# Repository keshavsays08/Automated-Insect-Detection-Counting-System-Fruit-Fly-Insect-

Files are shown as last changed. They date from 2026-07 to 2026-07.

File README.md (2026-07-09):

# Automated Insect Detection & Counting System

## 📌 Project Overview

A real-time fruit fly detection and counting system using **YOLOv8 deep learning** deployed on **Raspberry Pi 4**. This project combines computer vision, edge AI, and IoT to create an automated agricultural monitoring solution.

**Key Achievement**: 93% accuracy with automated counting, CSV logging, and custom 3D-printed hardware integration.

---

## 🎯 Problem Statement

Agricultural pest monitoring requires continuous manual observation, which is time-consuming and labor-intensive. This project automates fruit fly detection and counting using deep learning on edge devices for real-time monitoring.

---

## 💡 Solution Architecture

### High-Level Flow:

```
Data Collection → Annotation → Model Training → Pi Deployment → Real-Time Detection
     ↓              ↓              ↓                ↓               ↓
 1100+ Images  Roboflow       YOLOv8           Optimization    CSV Logging
```

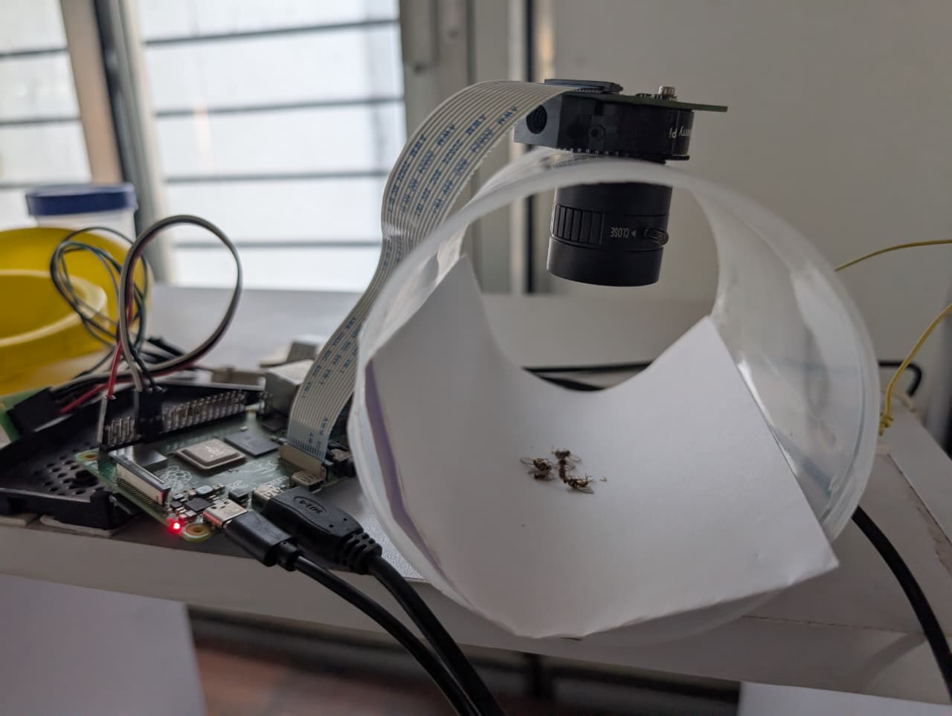
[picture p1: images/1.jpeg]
Initial Project Setup


---
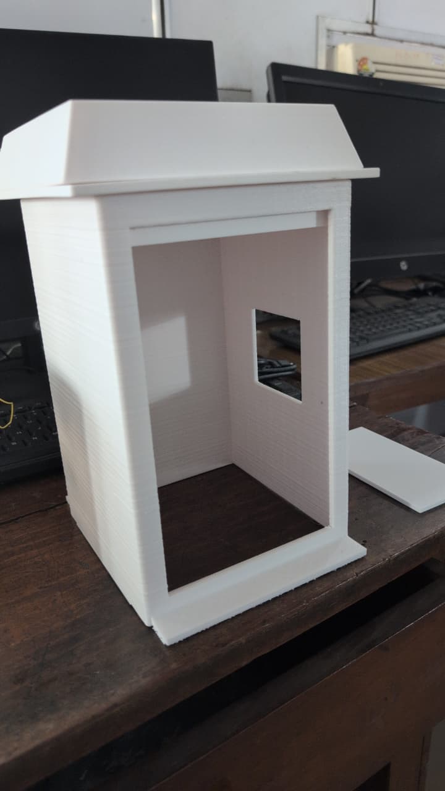
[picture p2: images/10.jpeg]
Final Project Setup


---

## 🛠️ Technology Stack

### Machine Learning
- **Framework**: PyTorch with YOLOv8
- **Dataset**: 520 annotated images
- **Annotation Tool**: Roboflow
- **Augmentation**: Flip, Rotation (±15°), 90° Rotate, Blur, Noise

### Hardware
- **Device**: Raspberry Pi 4 (4GB)
- **Camera**: HQ Camera Module (5MP)
- **3D Design**: Custom-printed enclosure

### Software
- **Computer Vision**: OpenCV
- **Data Processing**: Pandas, NumPy
- **Logging**: CSV with timestamps
- **Real-time Display**: OpenCV visualization

---

## 📊 Project Results

### Model Performance

| Metric | Value |
|---|---|
| **mAP@50** | 93% |
| **Precision** | 90.1% |
| **Recall** | 93.0% |
| **Training Data** | 520 annotated images |
| **Real-time FPS** | 5-10 FPS on Pi 4 |

---

## 🎬 Project Pipeline

### Phase 1: Data Collection
- Captured **1,100+ images** on Raspberry Pi HQ Camera
- Various scenarios: different lighting, angles, close-ups, far shots
- Consistent dome setup for standardization

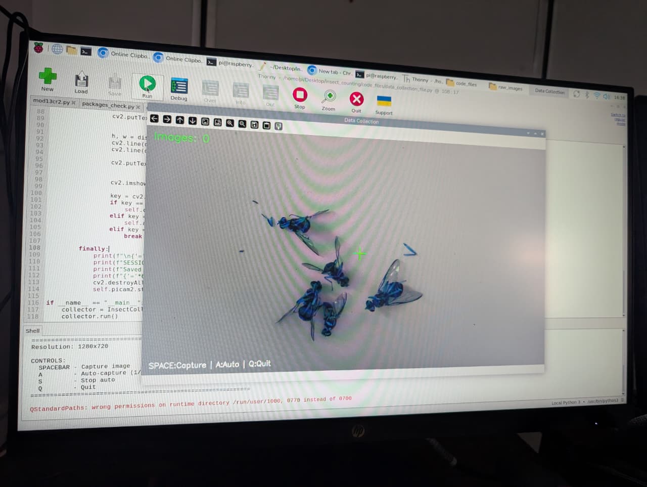
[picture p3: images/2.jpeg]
During Data Collection


### Phase 2: Data Annotation
- Annotated **520 images** using Roboflow
- Manual bounding box creation around each fruit fly
- ~2-3 hours of annotation work
- Single class: "fruit fly"

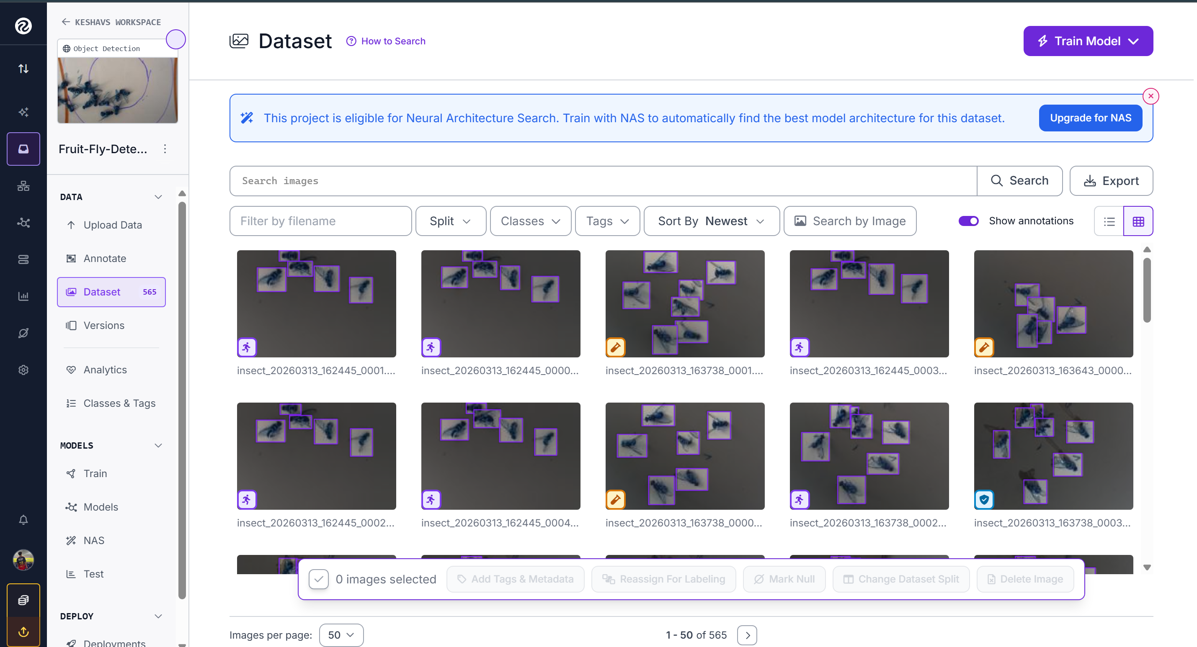
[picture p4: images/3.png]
During Data Annotation


### Phase 3: Model Training
- **Framework**: YOLOv8 Nano (optimized for Pi)
- **Training Environment**: PC with Python + PyTorch
- **Augmentation**: 3x multiplier for better generalization
- **Result**: 93% mAP@50 in just 8 epochs (early stop due to excellent performance)

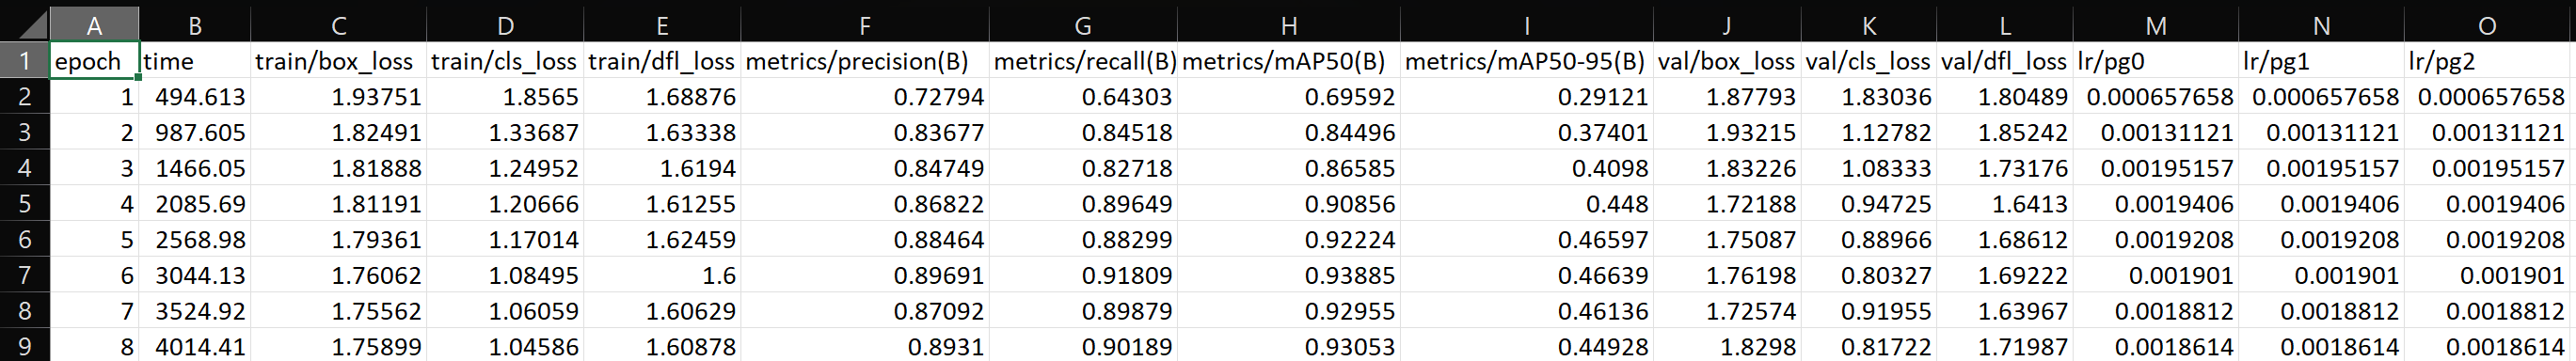
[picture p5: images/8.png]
Training Results


### Phase 4: PC Simulation Testing
- Created Python simulator to test model on PC
- Tested on 30 unannotated images
- Live detection display with 15-second intervals
- CSV logging of results

### Phase 5: Raspberry Pi Deployment
- Installed 64-bit Raspberry Pi OS
- Optimized PyTorch inference (CPU-only)
- Deployed real-time detection system
- Automated snapshot capture every 60 seconds

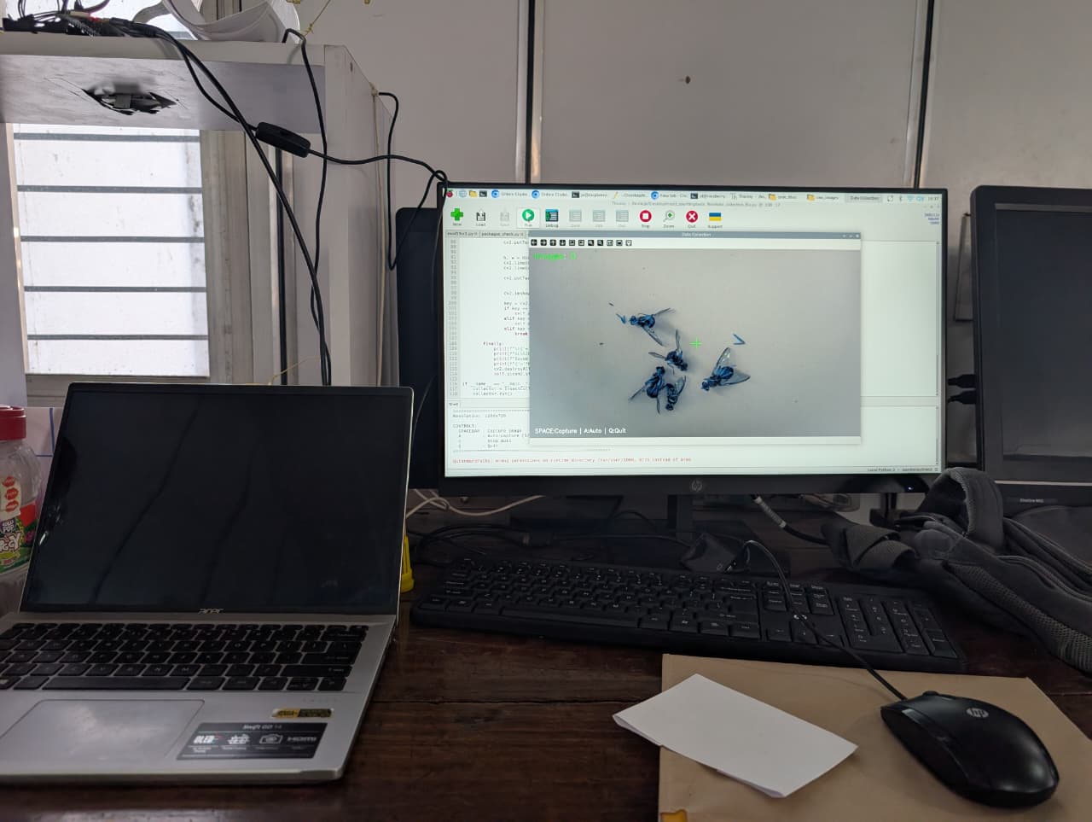
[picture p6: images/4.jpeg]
During Deployment


### Phase 6: Hardware Integration
- **3D Enclosure Design**: Custom-printed trap housing
- **Components**: Camera mount, Pi housing, pheromone chamber
- **Purpose**: Integration point for field deployment

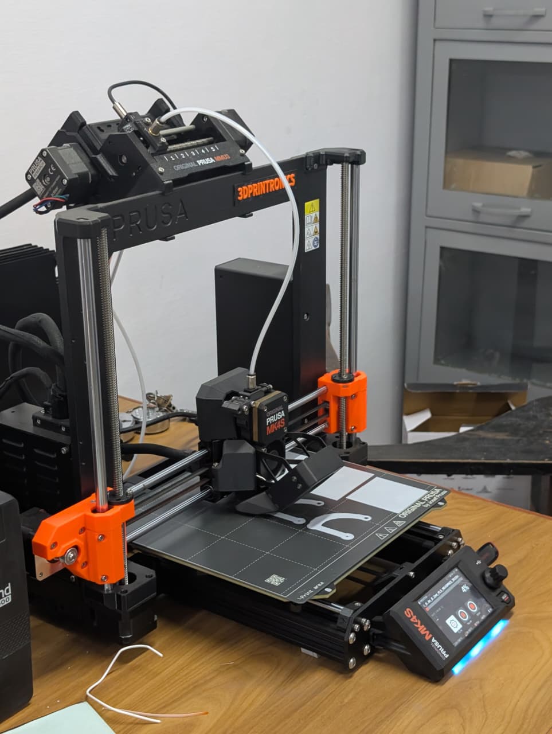
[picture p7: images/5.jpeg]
During 3D Printing


---

## ✨ Key Features

### Real-Time Detection
- Live camera feed with bounding boxes
- Fruit fly count displayed on screen
- FPS monitoring
- Confidence scores for each detection

### Automated Logging
- CSV file with timestamp, count, and confidence
- Automatic snapshot capture every 60 seconds
- Session statistics and duration tracking
- Organized data structure for analysis

### User Controls
- **SPACE**: Pause/Resume detection
- **S**: Save snapshot manually
- **Q**: Quit and display statistics

### Hardware Integration
- Custom 3D-printed enclosure
- Professional mounting for Pi and camera
- Pheromone trap integration design
- Field-deployment ready

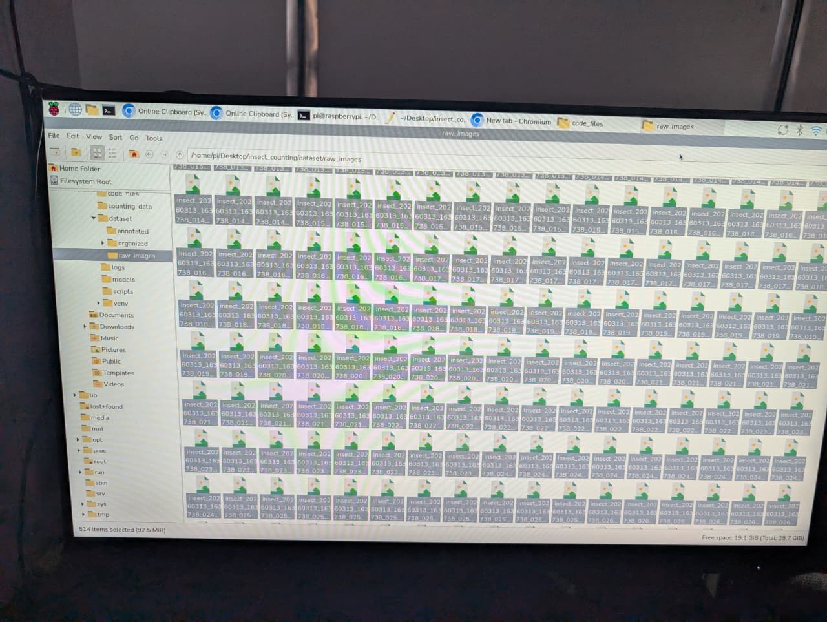
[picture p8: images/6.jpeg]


---

## 📈 Metrics & Performance

### Detection Accuracy
- **93% mAP@50**: Industry-competitive accuracy
- **90.1% Precision**: Minimal false positives
- **93% Recall**: Excellent fly detection rate

### System Performance
- **Processing Speed**: 5-10 FPS on Raspberry Pi 4
- **Memory Usage**: ~400-600MB RAM
- **CPU Usage**: 60-80%
- **Model Size**: ~20MB (optimized)

### Data Logging
- **CSV Format**: Timestamp, count, confidence, processing time
- **Snapshot Interval**: Every 60 seconds (configurable)
- **Session Tracking**: Duration, total frames, total detections

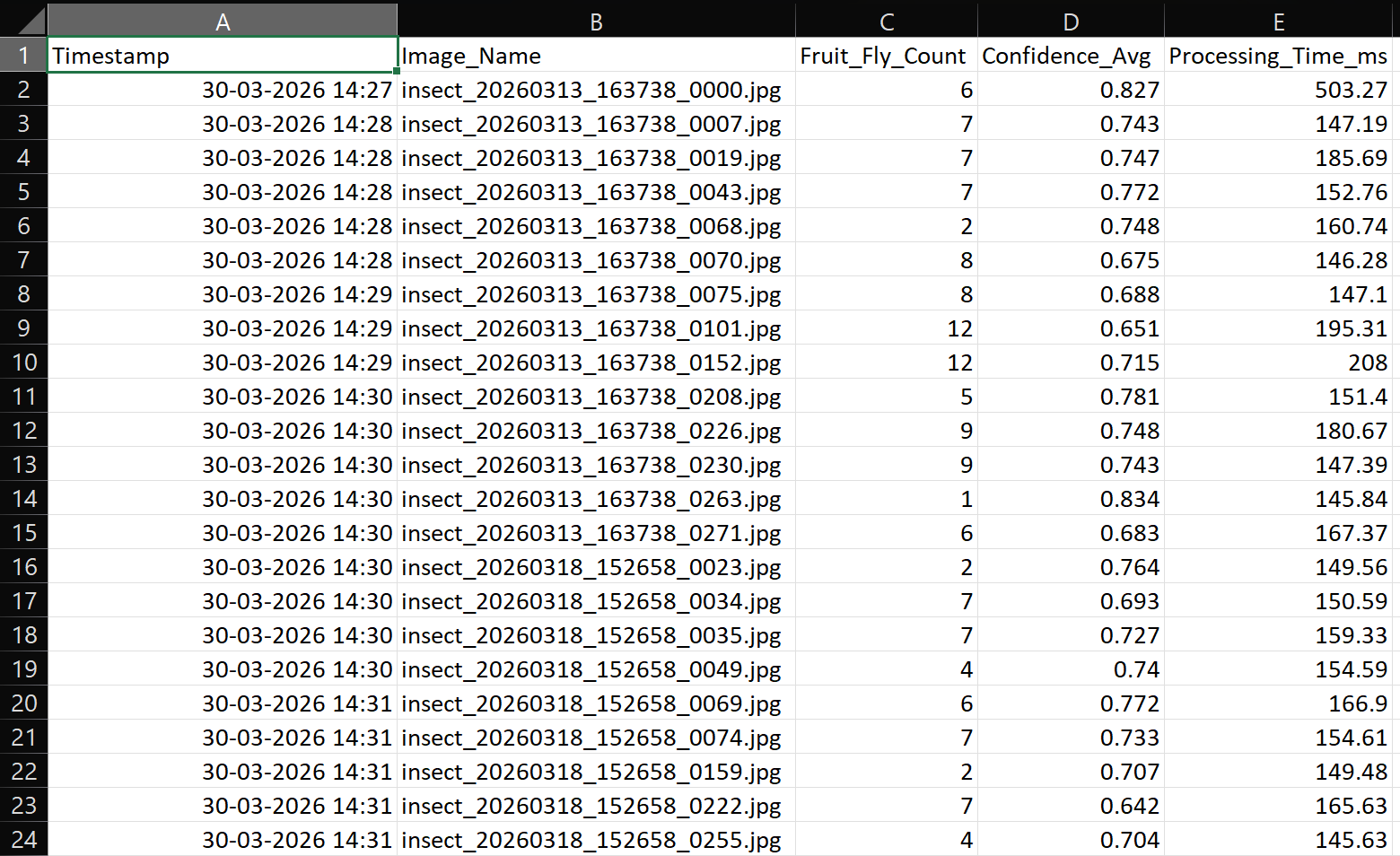
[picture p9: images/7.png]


---

## 🚀 How to Use

### Quick Start

```bash
# 1. Clone repository
git clone https://github.com/keshaysays08/Automated-Insect-Detection-Counting-System.git
cd Automated-Insect-Detection-Counting-System

# 2. Install dependencies
pip install -r requirements.txt

# 3. Download dataset
python scripts/download_dataset.py

# 4. Run real-time detection
python scripts/realtime_detection.py
```

### Output Files
After running the system, you'll get:
- `detection_logs/detection_log_YYYYMMDD_HHMMSS.csv` - Detailed detection data
- `detection_logs/captured_detections/` - Snapshot images with detections

### Configurable Parameters
Edit `config/config.yaml` to adjust:
- Confidence threshold (0.0-1.0)
- Frame delay between captures
- Snapshot capture interval

---

## 🔬 Dataset Information

### Statistics
- **Total Images Collected**: 1,100+
- **Images Annotated**: 520
- **Classes**: 1 (fruit fly)
- **Train/Val/Test Split**: 70/20/10

### Data Augmentation
- Horizontal flip
- Rotation (±15°)
- 90° rotations (all directions)
- Blur (up to 1px)
- Noise (up to 1.68%)
- **Augmentation Multiplier**: 3x

### Download Dataset
```bash
python scripts/download_dataset.py
```
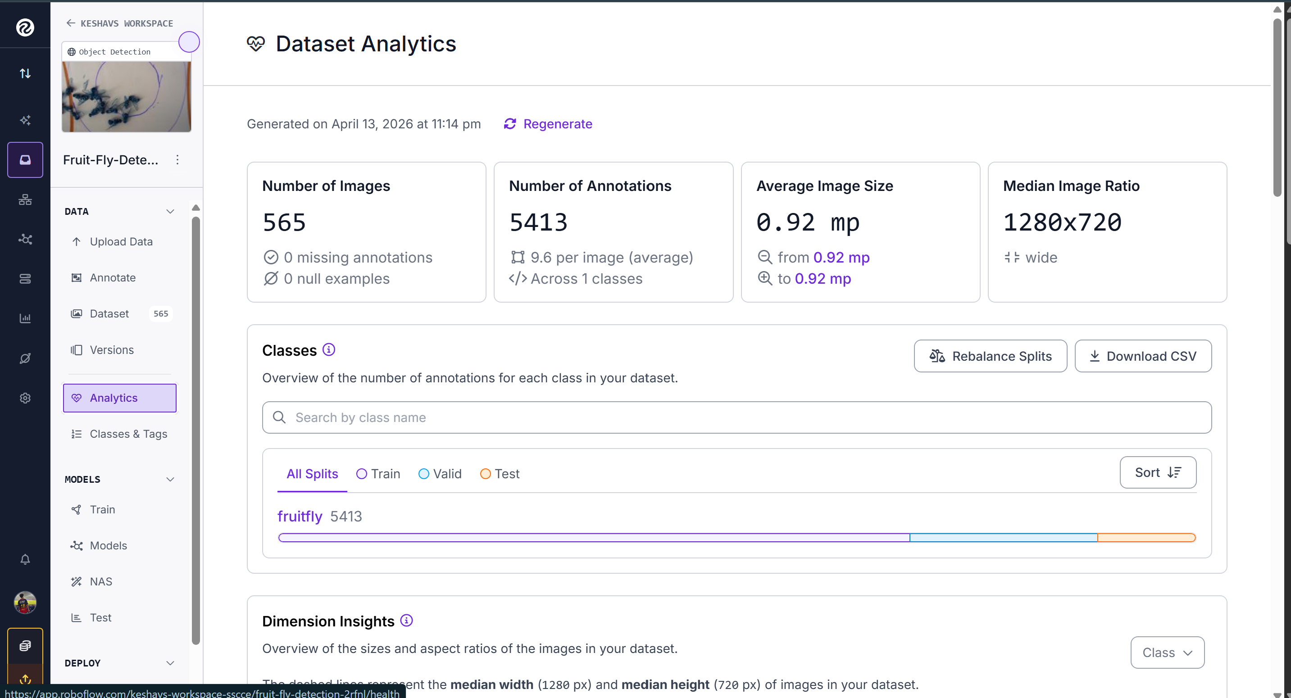
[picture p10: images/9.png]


---

## 🔧 Technical Details

### Environment Setup
- **Python**: 3.11+
- **OS**: 64-bit Raspberry Pi OS (Bookworm)
- **Virtual Environment**: Conda with system packages
- **GPU**: CPU-only (optimized for Pi)

### Dependencies
All dependencies listed in `requirements.txt`:
- torch==2.0.1
- ultralytics==8.0.200
- opencv-python==4.8.1
- pandas==2.0.3
- And others for full pipeline

### Model Architecture
- **Base Model**: YOLOv8 Nano
- **Framework**: PyTorch → TorchScript optimization
- **Input Size**: 640×480 (adjustable)
- **Output**: Bounding boxes with confidence scores

---

## 📁 Project Structure

```
Automated-Insect-Detection-Counting-System/
├── scripts/
│   ├── realtime_detection.py    # Main detection system
│   └── download_dataset.py       # Roboflow dataset download
├── runs/
│   └── best.pt                   # Trained YOLO model
├── config/
│   └── config.yaml               # Configuration parameters
├── hardware/
│   └── assembly_guide.md         # 3D enclosure assembly
├── docs/
│   ├── SETUP.md                  # Installation guide
│   └── USAGE.md                  # Usage instructions
├── README.md                      # This file
├── requirements.txt               # Python dependencies
└── .gitignore                     # Git ignore rules
```

---

## 🤝 Author

**Keshav Gairola**
- Portfolio: [keshav-gairola-portfolio.vercel.app](https://keshav-gairola-portfolio.vercel.app)
- GitHub: [@keshaysays08](https://github.com/keshaysays08)
- Email: keshavsays08@gmail.com

---

## 📝 License

This project is licensed under the MIT License - see the LICENSE file for details.

---

## 🙏 Acknowledgments

- YOLOv8 by Ultralytics
- Roboflow for annotation platform
- Raspberry Pi Foundation
- PyTorch community

---

**Last Updated**: April 2026

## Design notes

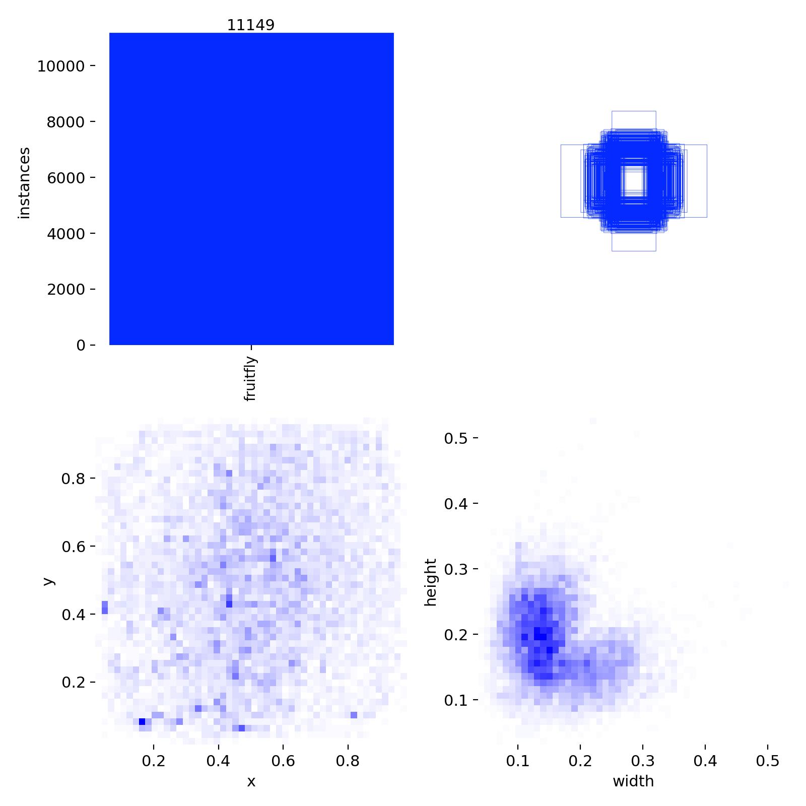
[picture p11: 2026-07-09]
runs/detect/fruitfly_model/v1/labels.jpg

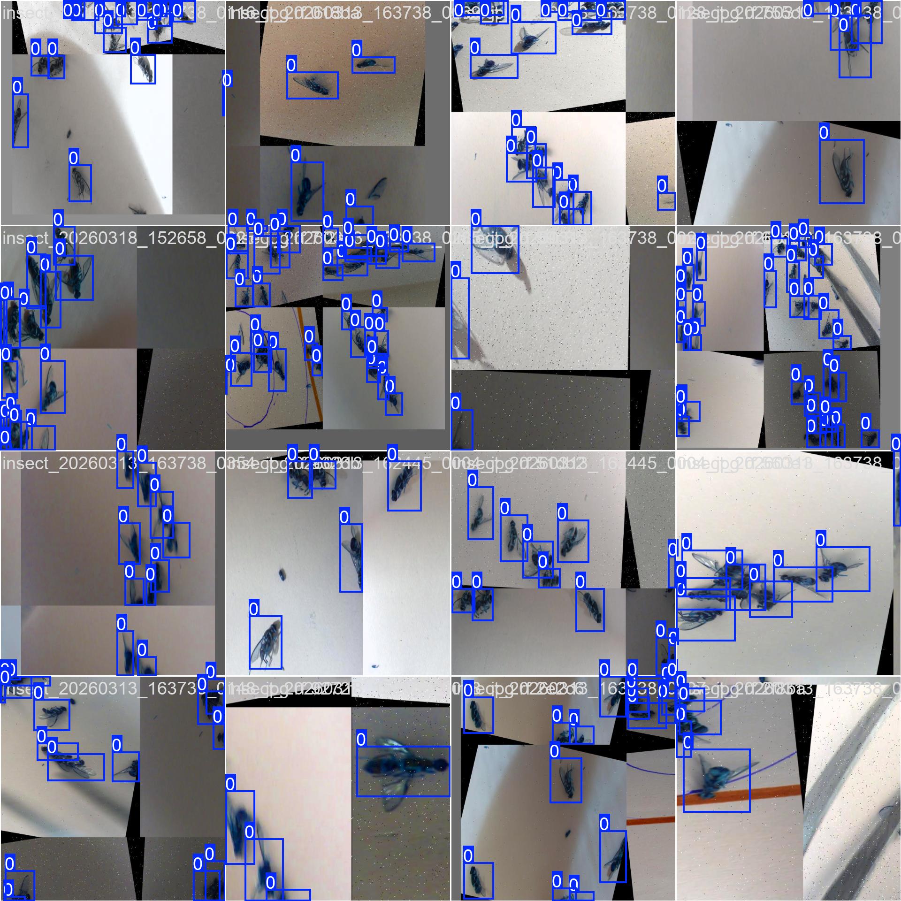
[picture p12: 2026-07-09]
runs/detect/fruitfly_model/v1/train_batch2.jpg

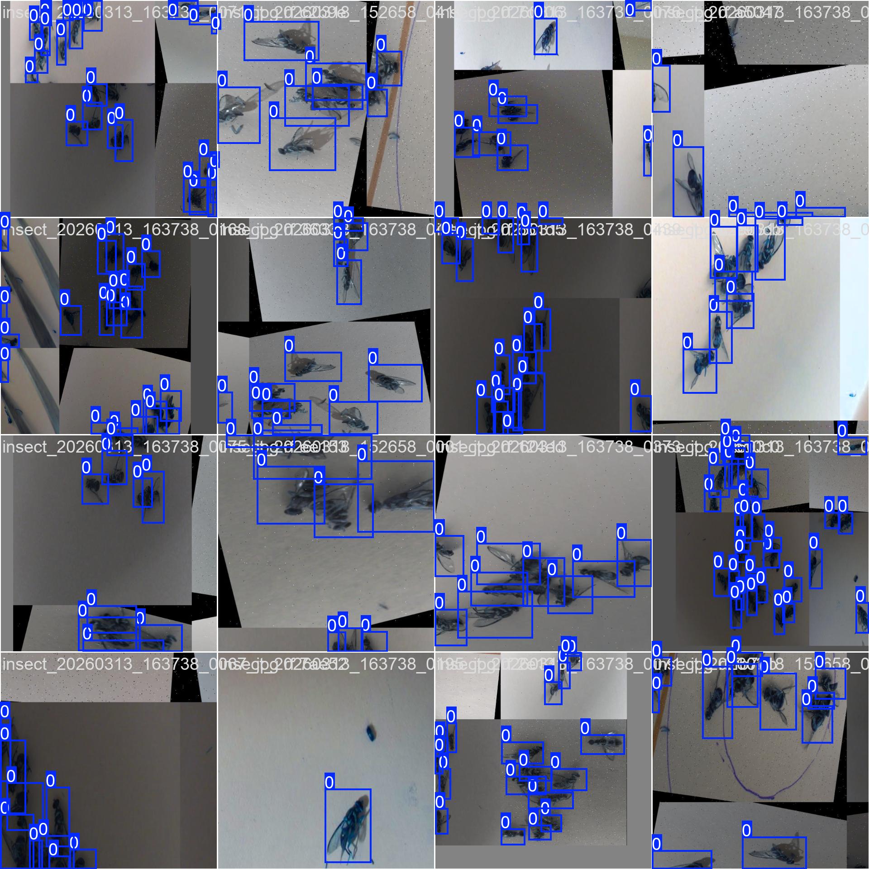
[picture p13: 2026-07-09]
runs/detect/fruitfly_model/v1/train_batch1.jpg

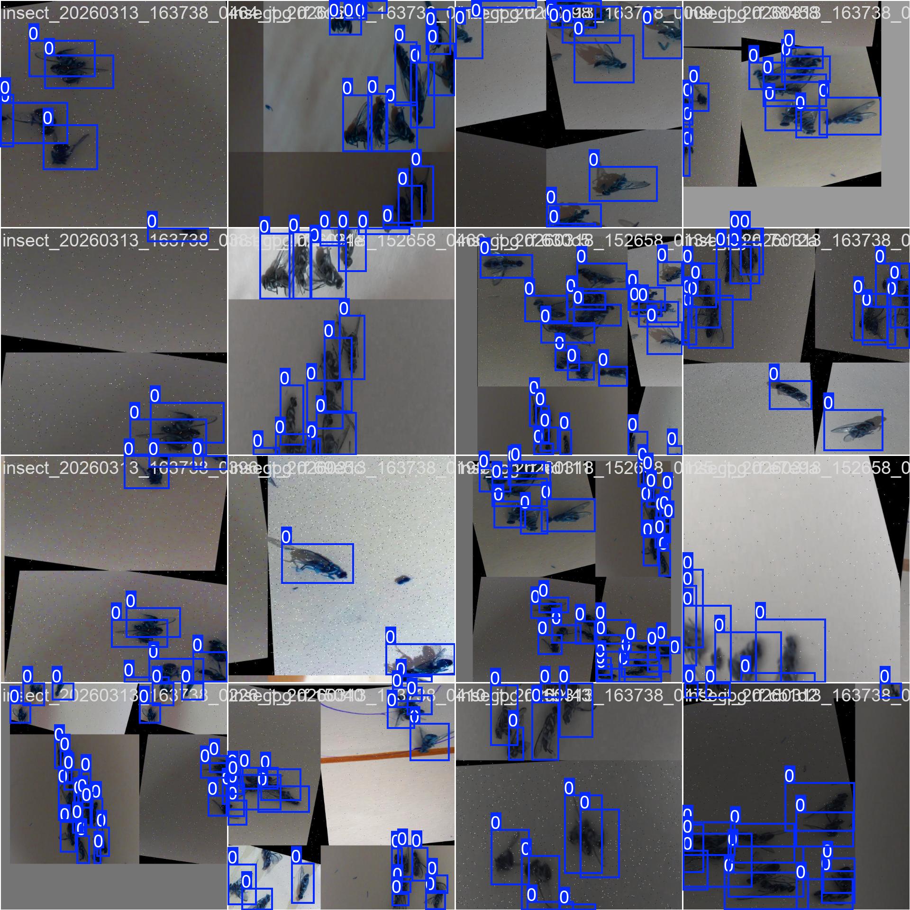
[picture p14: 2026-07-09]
runs/detect/fruitfly_model/v1/train_batch0.jpg

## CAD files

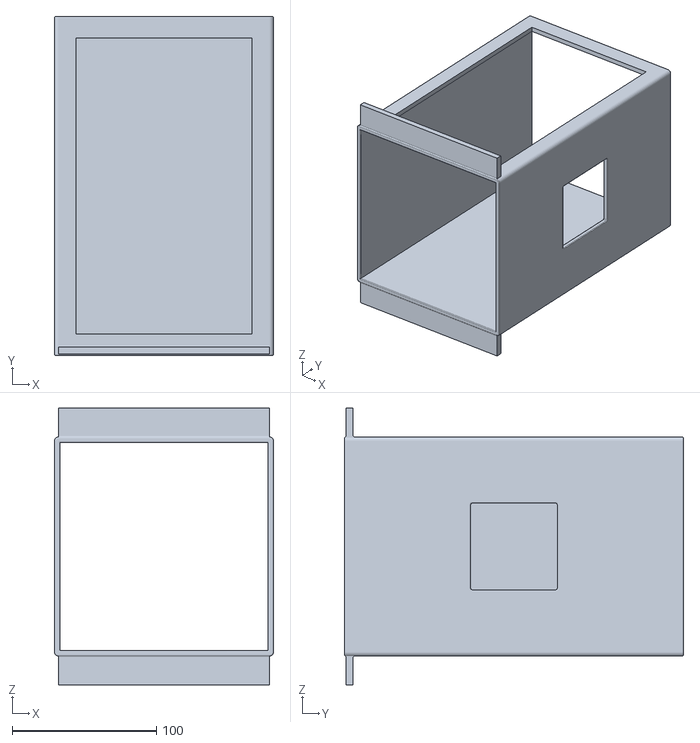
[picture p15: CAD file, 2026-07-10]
hardware/FINAL_TrapdoorMainChamber.stl
152.0 x 235.0 x 192.0

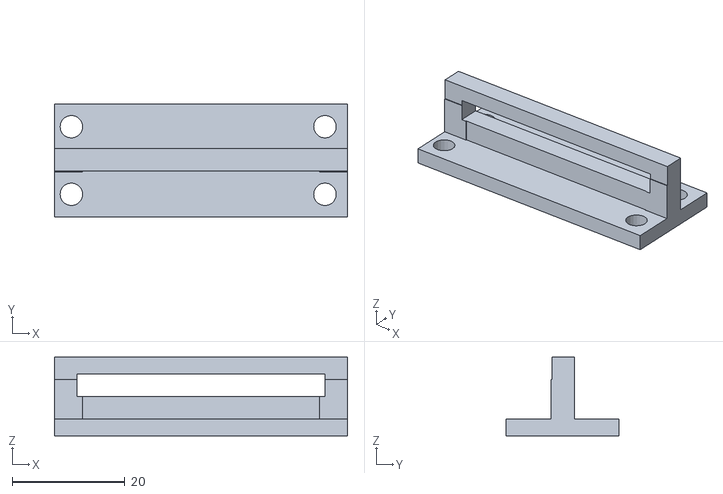
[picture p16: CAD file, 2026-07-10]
hardware/ServoMotor/Door_part2.stl
52.0 x 20.0 x 14.0

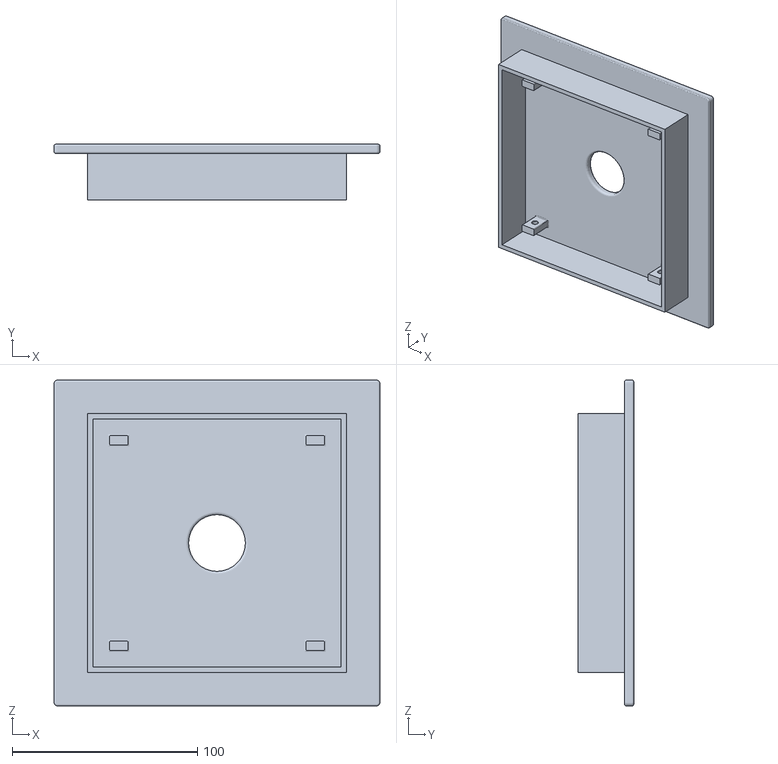
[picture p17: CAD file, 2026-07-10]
hardware/FINAL_TopLidSurface.stl
176.0 x 30.0 x 176.0

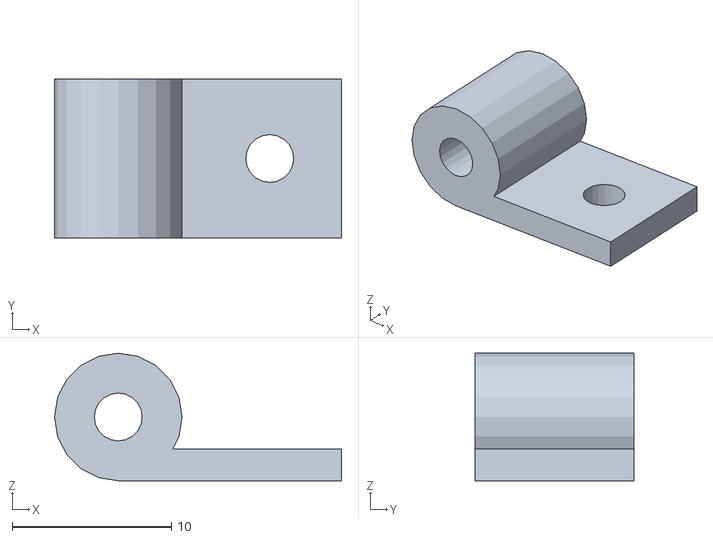
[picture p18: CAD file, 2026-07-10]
hardware/ServoMotor/Door_part0.stl
18.0 x 10.0 x 8.00

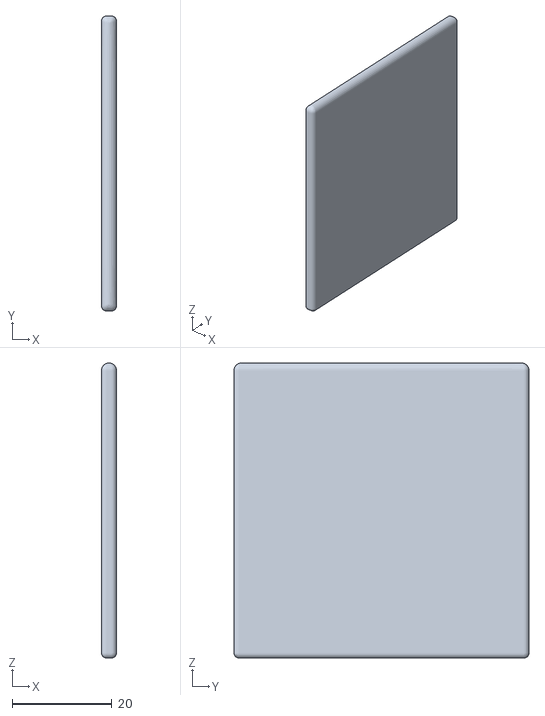
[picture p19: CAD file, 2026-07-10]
hardware/FINAL_FlapDoor.stl
3.00 x 59.0 x 59.0

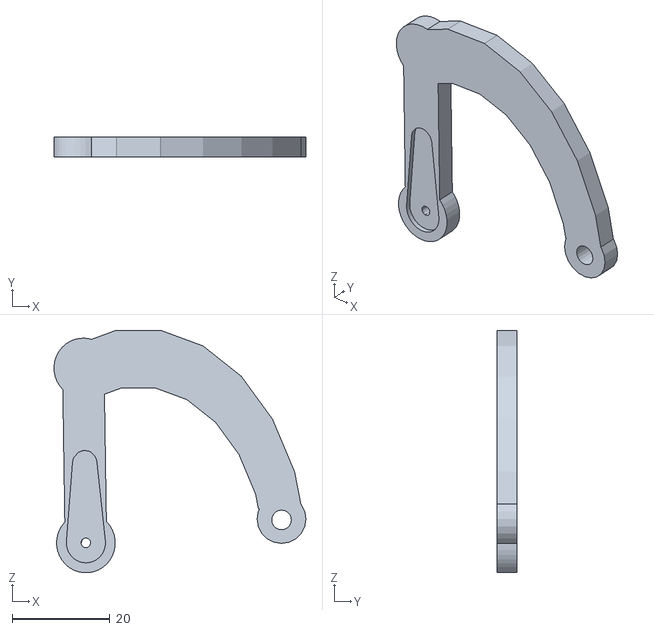
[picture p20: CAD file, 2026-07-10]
hardware/ServoMotor/ServoHorn.stl
51.5 x 4.00 x 49.6

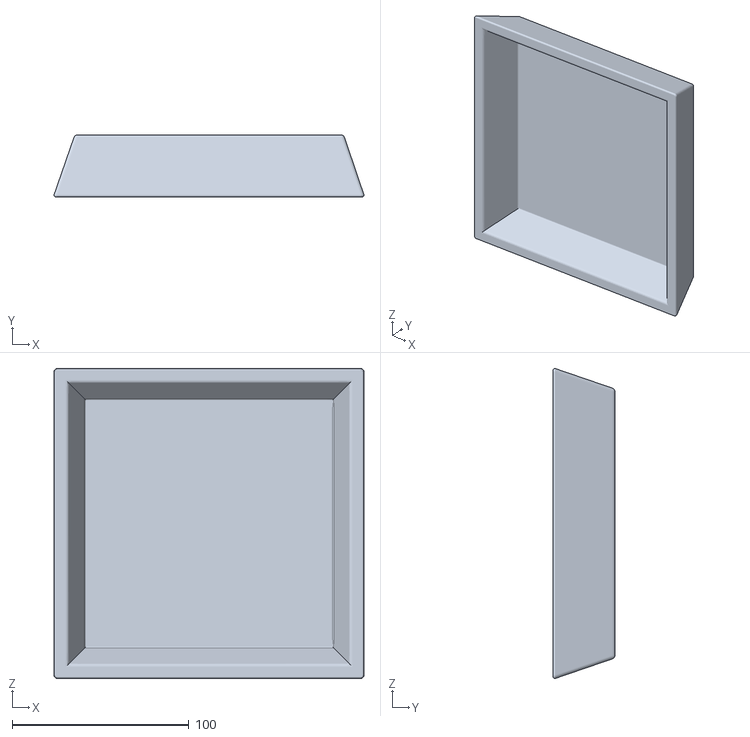
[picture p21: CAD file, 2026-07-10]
hardware/FINAL_TopLid.stl
175.2 x 35.0 x 175.2

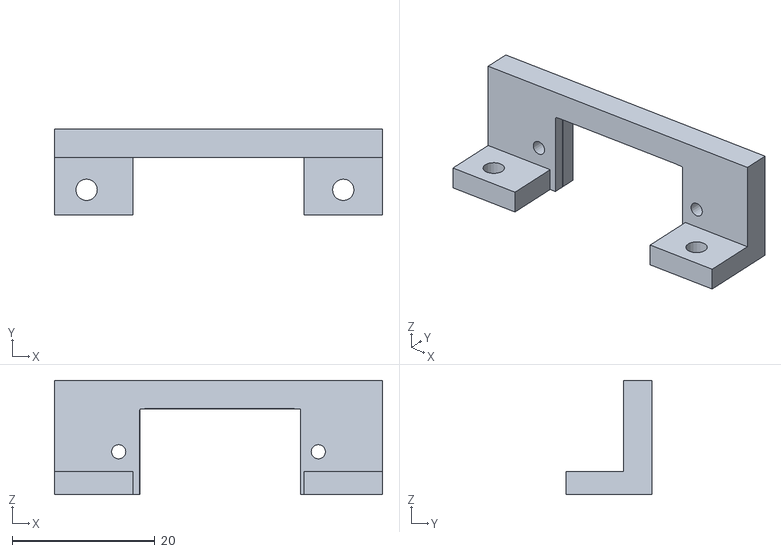
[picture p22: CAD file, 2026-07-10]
hardware/ServoMotor/Servo_Mount.stl
46.0 x 12.0 x 16.0

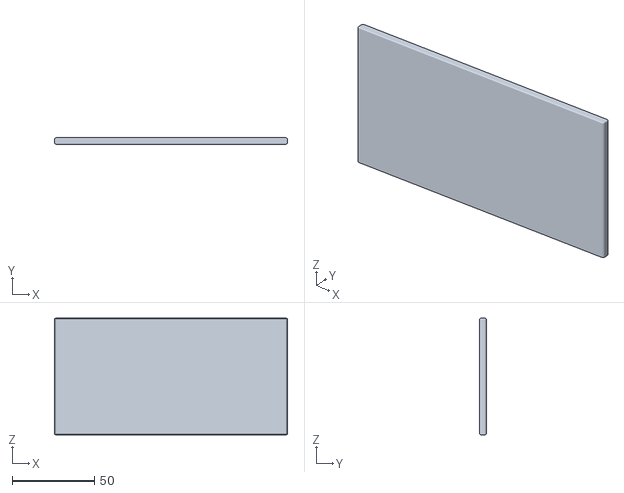
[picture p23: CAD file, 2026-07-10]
hardware/FINAL_TrapdoorFloor.stl
142.0 x 4.00 x 71.0

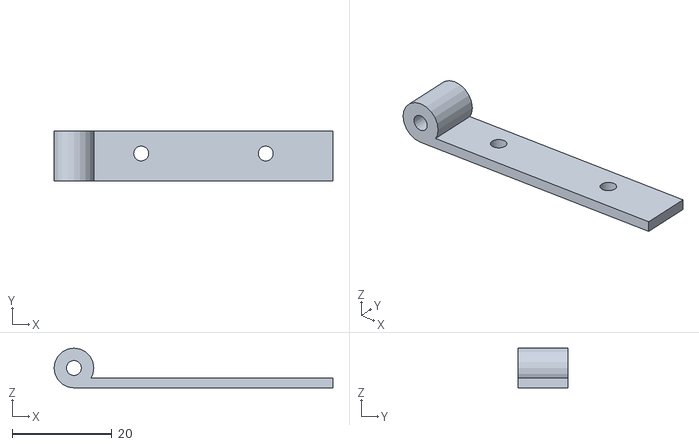
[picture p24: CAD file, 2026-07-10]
hardware/ServoMotor/Door_part1.stl
56.0 x 10.0 x 8.00

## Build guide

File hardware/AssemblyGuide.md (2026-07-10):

# ASSEMBLY GUIDE:
Dimensions: 152 mm (L) x 152 mm (W) x 235 mm (H) | System: Dual-Servo Automated Trapdoor  
Chassis Thickness: 4.0mm

## BILL OF MATERIALS (BOM)

3D Printed Parts (PLA/PETG, 50% Gyroid Infill):
  - 1x Main Chassis Shell (with Acrylic window slot & Inlet hole)
  - 1x Top Lid (with 30.4mm centered camera hole & LED channels)
  - 2x Trapdoor Panels (Left and Right floor halves, 5.0mm thick)
  - 1x Inlet Swing Door

Sourced Hardware:
  - 3x TowerPro SG90 / MG90S Micro Servos (Inlet & Trapdoor actuation)
  - 1x Transparent Acrylic Sheet (7" x 5" x 2mm or 3mm)
  - M3 Screws (12mm for servo mounts)
  - Waterproof LED Strip Segment

## ASSEMBLY STEPS

### STEP 1: WINDOW INTERFACE

- Fix the 7" x 5" Acrylic Sheet down onto the front face of the Main Chassis. Ensure flush fit.  

### STEP 2: INLET SERVO & DOOR

- Fix the Servo Mount piece and the door pieces as demonstrated in the video below.
- Mount the first Micro Servo into the designated place in the mount. Secure using M2/M3 self-tapping screws.
- Position the Inlet Swing Door over the inlet hole. Insert the 3D-printed hinge pin into the chassis socket.
- Connect the Servo Horn to the door via the servo door hinge (CAD File named Servo Horn).  
  
Refer to this video: https://www.youtube.com/shorts/rI9qZ3FkhSA

### STEP 3: 2-PANEL TRAPDOOR MECHANISM

- Take the Left and Right Trapdoor Panels. Align their integrated hinge axles with the corresponding socket holes at the base of the chassis.
- Fit the panels so they meet in the center with the modeled 0.5mm clearance gap.
- Mount the two secondary actuation servo into the the chassis in the same fashion as the inlet chamber door mechanism. One servo motor on each side.

### STEP 4: LID & INTERNAL UTILITIES

- Insert the 30mm camera lens module into the centered 30.4mm counterbore seat on the Top Lid Surface. Fasten via the 4x modeled M3 standoffs.
- Press-fit or adhesive-bond the LED strip into the internal perimeter under the lid. Route the wiring out through the rear notch.
- Thread your bait/lure onto the internal ceiling hooks.
- Fit the Top Lid on top of the Top Lid Surface to secure everything.

### STEP 5: FINAL INTEGRATION

- Align the Top Lid Surface with the Main Chassis rim.
- Position the enclosure over your collection chamber/bucket. Secure the corners using the physical L-brackets and M3 hardware into the pre-modeled pilot holes.
---
#### MECHANICAL VERIFICATION & TOLERANCES  

- **Clearance Verification**: Ensure the 0.5mm air gap between the trapdoor panels and the inner walls is clear of stray filament strings.
- **Axis Alignment**: The panels must fall completely vertical under gravity when the servo linkage retracts to clear the path for disposal.

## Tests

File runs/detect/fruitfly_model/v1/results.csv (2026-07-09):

epoch | time | train/box_loss | train/cls_loss | train/dfl_loss | metrics/precision(B) | metrics/recall(B) | metrics/mAP50(B) | metrics/mAP50-95(B) | val/box_loss | val/cls_loss | val/dfl_loss | lr/pg0 | lr/pg1 | lr/pg2
1 | 494.613 | 1.93751 | 1.8565 | 1.68876 | 0.72794 | 0.64303 | 0.69592 | 0.29121 | 1.87793 | 1.83036 | 1.80489 | 0.000657658 | 0.000657658 | 0.000657658
2 | 987.605 | 1.82491 | 1.33687 | 1.63338 | 0.83677 | 0.84518 | 0.84496 | 0.37401 | 1.93215 | 1.12782 | 1.85242 | 0.00131121 | 0.00131121 | 0.00131121
3 | 1466.05 | 1.81888 | 1.24952 | 1.6194 | 0.84749 | 0.82718 | 0.86585 | 0.4098 | 1.83226 | 1.08333 | 1.73176 | 0.00195157 | 0.00195157 | 0.00195157
4 | 2085.69 | 1.81191 | 1.20666 | 1.61255 | 0.86822 | 0.89649 | 0.90856 | 0.448 | 1.72188 | 0.94725 | 1.6413 | 0.0019406 | 0.0019406 | 0.0019406
5 | 2568.98 | 1.79361 | 1.17014 | 1.62459 | 0.88464 | 0.88299 | 0.92224 | 0.46597 | 1.75087 | 0.88966 | 1.68612 | 0.0019208 | 0.0019208 | 0.0019208
6 | 3044.13 | 1.76062 | 1.08495 | 1.6 | 0.89691 | 0.91809 | 0.93885 | 0.46639 | 1.76198 | 0.80327 | 1.69222 | 0.001901 | 0.001901 | 0.001901
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

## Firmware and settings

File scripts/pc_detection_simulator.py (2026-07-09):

#!/usr/bin/env python3
"""
Fruit Fly Detection - PC Simulator
Simulates the Raspberry Pi detection system on PC
Tests model on images with automatic timing and CSV logging
"""

import cv2
import os
from datetime import datetime
import csv
from pathlib import Path
from ultralytics import YOLO
import time

class FruitFlySimulator:
    def __init__(self, model_path, images_folder, output_folder="simulation_results"):
        """
        Initialize the simulator
        
        Args:
            model_path: Path to best.pt model file
            images_folder: Folder containing test images
            output_folder: Where to save results
        """
        # Load model
        print("Loading model...")
        self.model = YOLO(model_path)
        print(f"✓ Model loaded: {model_path}")
        
        # Setup folders
        self.images_folder = Path(images_folder)
        self.output_folder = Path(output_folder)
        self.output_folder.mkdir(exist_ok=True)
        
        # Create subfolders
        self.annotated_folder = self.output_folder / "annotated_images"
        self.annotated_folder.mkdir(exist_ok=True)
        
        # Get image files
        self.image_files = sorted([
            f for f in self.images_folder.glob('*')
            if f.suffix.lower() in ['.jpg', '.jpeg', '.png', '.bmp']
        ])
        
        print(f"✓ Found {len(self.image_files)} images")
        
        # CSV setup
        self.csv_path = self.output_folder / f"detection_log_{datetime.now().strftime('%Y%m%d_%H%M%S')}.csv"
        self._initialize_csv()
        
        # Statistics
        self.total_detections = 0
        self.current_index = 0
        self.detection_results = []
        
        # Display settings
        self.display_time = 15  # seconds per image
        self.confidence_threshold = 0.5
        
    def _initialize_csv(self):
        """Create CSV file with headers"""
        with open(self.csv_path, 'w', newline='') as f:
            writer = csv.writer(f)
            writer.writerow([
                'Timestamp',
                'Image_Name', 
                'Fruit_Fly_Count',
                'Confidence_Avg',
                'Processing_Time_ms'
            ])
        print(f"✓ CSV log created: {self.csv_path}")
    
    def _log_detection(self, image_name, count, avg_confidence, processing_time):
        """Log detection to CSV"""
        timestamp = datetime.now().strftime('%Y-%m-%d %H:%M:%S')
        
        with open(self.csv_path, 'a', newline='') as f:
            writer = csv.writer(f)
            writer.writerow([
                timestamp,
                image_name,
                count,
                f"{avg_confidence:.3f}" if count > 0 else "N/A",
                f"{processing_time:.2f}"
            ])
        
        # Store for statistics
        self.detection_results.append({
            'timestamp': timestamp,
            'image': image_name,
            'count': count
        })
    
    def detect_on_image(self, image_path):
        """Run detection on single image"""
        # Read image
        img = cv2.imread(str(image_path))
        if img is None:
            print(f"Error: Could not read {image_path}")
            return None
        
        # Run detection
        start_time = time.time()
        results = self.model(img, conf=self.confidence_threshold, verbose=False)
        processing_time = (time.time() - start_time) * 1000  # ms
        
        # Extract results
        boxes = results[0].boxes
        count = len(boxes)
        
        # Calculate average confidence
        avg_confidence = 0
        if count > 0:
            confidences = boxes.conf.cpu().numpy()
            avg_confidence = confidences.mean()
        
        # Draw annotations
        annotated_img = results[0].plot()
        
        # Add overlay information
        self._add_overlay(annotated_img, image_path.name, count, avg_confidence, processing_time)
        
        # Log to CSV
        self._log_detection(image_path.name, count, avg_confidence, processing_time)
        
        # Save annotated image
        save_path = self.annotated_folder / f"annotated_{image_path.name}"
        cv2.imwrite(str(save_path), annotated_img)
        
        return {
            'image': annotated_img,
            'count': count,
            'confidence': avg_confidence,
            'processing_time': processing_time
        }
    
    def _add_overlay(self, img, filename, count, confidence, proc_time):
        """Add information overlay to image"""
        h, w = img.shape[:2]
        
        # Semi-transparent background for text
        overlay = img.copy()
        cv2.rectangle(overlay, (0, 0), (w, 120), (0, 0, 0), -1)
        cv2.addWeighted(overlay, 0.6, img, 0.4, 0, img)
        
        # Add text information
        y_offset = 30
        cv2.putText(img, f"Image: {filename}", (10, y_offset),
                   cv2.FONT_HERSHEY_SIMPLEX, 0.7, (255, 255, 255), 2)
        
        y_offset += 30
        cv2.putText(img, f"Fruit Flies Detected: {count}", (10, y_offset),
                   cv2.FONT_HERSHEY_SIMPLEX, 0.8, (0, 255, 0), 2)
        
        y_offset += 30
        if count > 0:
            cv2.putText(img, f"Avg Confidence: {confidence:.2%}", (10, y_offset),
                       cv2.FONT_HERSHEY_SIMPLEX, 0.6, (255, 255, 255), 2)
        
        # Progress indicator
        progress_text = f"Image {self.current_index + 1}/{len(self.image_files)}"
        cv2.putText(img, progress_text, (w - 250, 30),
                   cv2.FONT_HERSHEY_SIMPLEX, 0.7, (255, 255, 0), 2)
    
    def _print_statistics(self):
        """Print session statistics"""
        print("\n" + "="*60)
        print("SESSION STATISTICS")
        print("="*60)
        
        total_images = len(self.detection_results)
        total_flies = sum(r['count'] for r in self.detection_results)
        avg_per_image = total_flies / total_images if total_images > 0 else 0
        
        images_with_flies = sum(1 for r in self.detection_results if r['count'] > 0)
        detection_rate = (images_with_flies / total_images * 100) if total_images > 0 else 0
        
        print(f"Total images processed: {total_images}")
        print(f"Total fruit flies detected: {total_flies}")
        print(f"Average flies per image: {avg_per_image:.2f}")
        print(f"Images with flies: {images_with_flies} ({detection_rate:.1f}%)")
        print(f"Images without flies: {total_images - images_with_flies}")
        print(f"\nResults saved to: {self.output_folder}")
        print(f"CSV log: {self.csv_path}")
        print(f"Annotated images: {self.annotated_folder}")
        print("="*60 + "\n")
    
    def run_auto_mode(self):
        """Run automatic slideshow mode"""
        print("\n" + "="*60)
        print("AUTOMATIC MODE - PC SIMULATION")
        print("="*60)
        print(f"Display time: {self.display_time} seconds per image")
        print("Controls:")
        print("  SPACE - Next image immediately")
        print("  P     - Pause/Resume auto-advance")
        print("  Q     - Quit")
        print("="*60 + "\n")
        
        paused = False
        
        for idx, image_path in enumerate(self.image_files):
            self.current_index = idx
            
            print(f"\n[{idx+1}/{len(self.image_files)}] Processing: {image_path.name}")
            
            # Detect
            result = self.detect_on_image(image_path)
            if result is None:
                continue
            
            print(f"  → Detected: {result['count']} flies")
            print(f"  → Confidence: {result['confidence']:.2%}")
            print(f"  → Processing: {result['processing_time']:.2f}ms")
            
            # Display
            cv2.imshow('Fruit Fly Detection Simulator', result['image'])
            
            # Wait with keyboard control
            start_wait = time.time()
            while True:
                elapsed = time.time() - start_wait
                
                # Auto-advance after display_time (unless paused)
                if not paused and elapsed >= self.display_time:
                    break
                
                key = cv2.waitKey(100) & 0xFF
                
                if key == ord('q'):  # Quit
                    print("\nQuitting...")
                    cv2.destroyAllWindows()
                    self._print_statistics()
                    return
                
                elif key == ord(' '):  # Next immediately
                    break
                
                elif key == ord('p'):  # Pause/Resume
                    paused = not paused
                    status = "PAUSED" if paused else "RESUMED"
                    print(f"  [{status}]")
        
        cv2.destroyAllWindows()
        self._print_statistics()
    
    def run_manual_mode(self):
        """Run manual control mode"""
        print("\n" + "="*60)
        print("MANUAL MODE - PC SIMULATION")
        print("="*60)
        print("Controls:")
        print("  D or →  - Next image")
        print("  A or ←  - Previous image")
        print("  Q       - Quit")
        print("="*60 + "\n")
        
        while 0 <= self.current_index < len(self.image_files):
            image_path = self.image_files[self.current_index]
            
            print(f"\n[{self.current_index+1}/{len(self.image_files)}] {image_path.name}")
            
            # Detect
            result = self.detect_on_image(image_path)
            if result is None:
                self.current_index += 1
                continue
            
            print(f"  → Flies: {result['count']}")
            
            # Display
            cv2.imshow('Fruit Fly Detection Simulator', result['image'])
            
            # Wait for key
            while True:
                key = cv2.waitKey(0) & 0xFF
                
                if key == ord('q'):
                    cv2.destroyAllWindows()
                    self._print_statistics()
                    return
                
                elif key == ord('d') or key == 83:  # D or Right arrow
                    self.current_index += 1
                    break
                
                elif key == ord('a') or key == 81:  # A or Left arrow
                    self.current_index = max(0, self.current_index - 1)
                    break
        
        cv2.destroyAllWindows()
        self._print_statistics()


if __name__ == "__main__":
    import sys
    
    print("="*60)
    print("FRUIT FLY DETECTION - PC SIMULATOR")
    print("="*60)
    
    # Configuration
    MODEL_PATH = "fruitfly_model/v1/weights/best.pt"
    IMAGES_FOLDER = "test_images"  # Put your 30 test images here
    
    # Check if model exists
    if not os.path.exists(MODEL_PATH):
        print(f"\n✗ Error: Model not found at {MODEL_PATH}")
        print("Please update MODEL_PATH in the script")
        sys.exit(1)
    
    # Check if images folder exists
    if not os.path.exists(IMAGES_FOLDER):
        print(f"\n✗ Error: Images folder not found: {IMAGES_FOLDER}")
        print("Creating folder... Please add your test images there")
        os.makedirs(IMAGES_FOLDER)
        sys.exit(1)
    
    # Create simulator
    simulator = FruitFlySimulator(MODEL_PATH, IMAGES_FOLDER)
    
    if len(simulator.image_files) == 0:
        print(f"\n✗ Error: No images found in {IMAGES_FOLDER}")
        print("Please add .jpg, .png, or .bmp images")
        sys.exit(1)
    
    # Choose mode
    print("\nSelect mode:")
    print("1. Automatic (15 sec per image)")
    print("2. Manual (keyboard control)")
    
    choice = input("\nEnter 1 or 2: ").strip()
    
    if choice == "1":
        simulator.run_auto_mode()
    elif choice == "2":
        simulator.run_manual_mode()
    else:
        print("Invalid choice")
        sys.exit(1)

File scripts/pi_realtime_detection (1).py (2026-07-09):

#!/usr/bin/env python3
"""
Real-Time Fruit Fly Detection and Counting for Raspberry Pi
Uses HQ Camera and YOLO model for live detection
Logs detections to CSV with timestamps
"""

import cv2
import numpy as np
from picamera2 import Picamera2
from ultralytics import YOLO
import time
from datetime import datetime
import csv
from pathlib import Path
import os

class RealTimeFruitFlyDetector:
    def __init__(self, model_path="models/best.pt", output_dir="detection_logs"):
        """
        Initialize real-time detector
        
        Args:
            model_path: Path to trained YOLO model
            output_dir: Directory for logs and captured images
        """
        print("="*60)
        print("FRUIT FLY REAL-TIME DETECTION SYSTEM")
        print("="*60)
        
        # Load model
        print(f"\nLoading model from {model_path}...")
        self.model = YOLO(model_path)
        print("✓ Model loaded successfully")
        
        # Initialize camera
        print("\nInitializing camera...")
        self.picam2 = Picamera2()
        
        # Camera configuration optimized for detection
        config = self.picam2.create_preview_configuration(
            main={"size": (640, 480), "format": "RGB888"}
        )
        self.picam2.configure(config)
        self.picam2.start()
        time.sleep(2)  # Camera warm-up
        print("✓ Camera initialized (640x480)")
        
        # Setup output directories
        self.output_dir = Path(output_dir)
        self.output_dir.mkdir(exist_ok=True)
        
        self.captures_dir = self.output_dir / "captured_detections"
        self.captures_dir.mkdir(exist_ok=True)
        
        # Session info
        self.session_start = datetime.now()
        session_id = self.session_start.strftime("%Y%m%d_%H%M%S")
        
        # CSV logging
        self.csv_path = self.output_dir / f"detection_log_{session_id}.csv"
        self._initialize_csv()
        
        # Detection settings
        self.confidence_threshold = 0.5
        self.capture_interval = 60  # Save snapshot every 60 seconds
        self.last_capture_time = time.time()
        
        # Statistics
        self.frame_count = 0
        self.total_detections = 0
        self.detection_history = []
        
        print(f"✓ Logging to: {self.csv_path}")
        print("="*60)
    
    def _initialize_csv(self):
        """Create CSV file with headers"""
        with open(self.csv_path, 'w', newline='') as f:
            writer = csv.writer(f)
            writer.writerow([
                'Timestamp',
                'Frame_Number',
                'Fruit_Fly_Count',
                'Average_Confidence',
                'Max_Confidence',
                'Min_Confidence',
                'Processing_Time_ms',
                'Snapshot_Saved'
            ])
    
    def _log_detection(self, frame_num, count, confidences, proc_time, snapshot_saved=False):
        """Log detection to CSV"""
        timestamp = datetime.now().strftime('%Y-%m-%d %H:%M:%S')
        
        if count > 0:
            avg_conf = np.mean(confidences)
            max_conf = np.max(confidences)
            min_conf = np.min(confidences)
        else:
            avg_conf = max_conf = min_conf = 0
        
        with open(self.csv_path, 'a', newline='') as f:
            writer = csv.writer(f)
            writer.writerow([
                timestamp,
                frame_num,
                count,
                f"{avg_conf:.3f}" if count > 0 else "N/A",
                f"{max_conf:.3f}" if count > 0 else "N/A",
                f"{min_conf:.3f}" if count > 0 else "N/A",
                f"{proc_time:.2f}",
                "Yes" if snapshot_saved else "No"
            ])
    
    def detect_frame(self, frame):
        """Run detection on single frame"""
        start_time = time.time()
        
        # Run YOLO detection
        results = self.model(frame, conf=self.confidence_threshold, verbose=False)
        
        processing_time = (time.time() - start_time) * 1000  # ms
        
        # Extract results
        boxes = results[0].boxes
        count = len(boxes)
        
        # Get confidences
        confidences = []
        if count > 0:
            confidences = boxes.conf.cpu().numpy()
        
        # Draw annotations
        annotated_frame = results[0].plot()
        
        return {
            'annotated': annotated_frame,
            'count': count,
            'confidences': confidences,
            'processing_time': processing_time,
            'results': results[0]
        }
    
    def _add_overlay(self, frame, count, avg_conf, fps, session_time):
        """Add information overlay to frame"""
        h, w = frame.shape[:2]
        
        # Semi-transparent background
        overlay = frame.copy()
        cv2.rectangle(overlay, (0, 0), (w, 150), (0, 0, 0), -1)
        cv2.addWeighted(overlay, 0.6, frame, 0.4, 0, frame)
        
        # Detection count (large, prominent)
        cv2.putText(frame, f"FRUIT FLIES: {count}", (10, 40),
                   cv2.FONT_HERSHEY_SIMPLEX, 1.2, (0, 255, 0), 3)
        
        # Confidence
        if count > 0:
            cv2.putText(frame, f"Confidence: {avg_conf:.1%}", (10, 75),
                       cv2.FONT_HERSHEY_SIMPLEX, 0.7, (255, 255, 255), 2)
        
        # Session info
        cv2.putText(frame, f"FPS: {fps:.1f}", (10, 105),
                   cv2.FONT_HERSHEY_SIMPLEX, 0.6, (255, 255, 0), 2)
        
        cv2.putText(frame, f"Session: {session_time}", (10, 130),
                   cv2.FONT_HERSHEY_SIMPLEX, 0.6, (255, 255, 0), 2)
        
        # Total detections
        cv2.putText(frame, f"Total frames: {self.frame_count}", (w - 250, 30),
                   cv2.FONT_HERSHEY_SIMPLEX, 0.6, (255, 255, 255), 2)
    
    def _save_snapshot(self, frame, count):
        """Save snapshot with timestamp"""
        timestamp = datetime.now().strftime("%Y%m%d_%H%M%S")
        filename = f"detection_{timestamp}_count{count}.jpg"
        filepath = self.captures_dir / filename
        cv2.imwrite(str(filepath), frame)
        return True
    
    def run(self):
        """Main detection loop"""
        print("\nStarting real-time detection...")
        print("Controls:")
        print("  S - Save current snapshot manually")
        print("  Q - Quit and show statistics")
        print("  SPACE - Pause/Resume")
        print("\nDetecting...\n")
        
        paused = False
        fps_start_time = time.time()
        fps_frame_count = 0
        current_fps = 0
        
        try:
            while True:
                # FPS calculation
                fps_frame_count += 1
                if time.time() - fps_start_time >= 1.0:
                    current_fps = fps_frame_count / (time.time() - fps_start_time)
                    fps_start_time = time.time()
                    fps_frame_count = 0
                
                # Capture frame
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
